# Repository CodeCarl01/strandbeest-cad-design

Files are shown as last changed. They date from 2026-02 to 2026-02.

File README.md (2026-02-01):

# 🦿 Strandbeest — Mécanisme de Jansen imprimé en 3D

**Conception, fabrication et tests d'un Strandbeest mécanique autonome — 0% électronique, 100% mécanique.**

Projet académique de 1ère année cycle ingénieur à Polytech Dijon. Un robot marcheur inspiré du mécanisme de Theo Jansen, entièrement conçu en CAO sous SolidWorks, fabriqué par impression 3D et propulsé par une corde élastique. Budget total : **15,82 €**.






---

<!-- Ajouter ici une photo ou un GIF du Strandbeest en mouvement -->
<!-- ![Demo](docs/strandbeest-demo.gif) -->

## 📋 Sommaire

- [Le projet](#-le-projet)
- [Mécanisme de Jansen](#-mécanisme-de-jansen)
- [Conception CAO](#-conception-cao)
- [Fabrication](#-fabrication)
- [Résultats des tests](#-résultats-des-tests)
- [Bill of Materials](#-bill-of-materials)
- [Limites et améliorations](#-limites-et-améliorations)
- [Équipe](#-équipe)

---

## 🎯 Le projet

### Cahier des charges

| Critère | Exigence | Résultat |
|---|---|---|
| Parcourir 30 cm minimum | ✅ Requis | **65 cm** atteints (4,5 tours) |
| Temps sur 30 cm | ~10 secondes | ✅ Validé |
| Stabilité | Marche stable sur sol plat | ✅ Validé |
| Cycle complet sans blocage | ✅ Requis | ✅ Validé |
| Aucune électronique | ✅ Obligatoire | ✅ Respecté |
| Budget < 100 € | ✅ Obligatoire | **15,82 €** |

### Principe de fonctionnement

```
  Clé de remontage
       │
       ▼
┌─────────────────┐
│  Corde élastique │  ← Stockage d'énergie (25 J, rendement ~70%)
│    (sandow)      │
└────────┬────────┘
         │
         ▼
┌─────────────────┐
│  Système poulie  │  ← Transmission et renvoi d'angle
│  + engrenage     │
└────────┬────────┘
         │
         ▼
┌─────────────────┐
│  Axe principal   │  ← Rotation continue (couple max : 1 N.m)
│  (manivelle)     │
└────────┬────────┘
         │
         ▼
┌─────────────────┐
│  Pattes Jansen   │  ← 4 pattes articulées, mouvement de marche
│  (x4, déphasées) │
└─────────────────┘
```

---

## ⚙️ Mécanisme de Jansen

Le Strandbeest repose sur le mécanisme à barres inventé par Theo Jansen. Chaque patte est composée de tiges rigides reliées par des articulations qui convertissent un mouvement rotatif en une trajectoire de marche.

### Proportions de Jansen (originales → adaptées)

Les 13 longueurs de référence de Jansen ont été adaptées à notre échelle avec un coefficient multiplicateur de **55/38** (base `a` = 55 mm au lieu de 38 mm) :

```
Longueurs originales (mm)        Notre adaptation (mm)
a = 38.0                         a = 55.0 (base)
b = 41.5                         b = 60.1
c = 39.3                         c = 56.9
d = 40.1                         d = 58.0
e = 55.8                         e = 80.7
f = 39.4                         f = 57.0
g = 36.7                         g = 53.1
h = 65.7                         h = 95.1
i = 49.0                         i = 70.9
j = 50.0                         j = 72.4
k = 61.9                         k = 87.0 ⚠️ (modifié, voir ci-dessous)
l =  7.8                         l = 11.3
m = 15.0                         m = 21.7
```

### Modification du paramètre `k`

Lors de la simulation cinématique sous SolidWorks, le mécanisme se bloquait avec les cotes proportionnelles exactes. La valeur `k` (distance axe manivelle – point de pivot) a été augmentée de **57 mm à 87 mm** pour débloquer la cinématique.

**Impact sur la trajectoire :**

| Caractéristique | Modèle Jansen original | Notre adaptation |
|---|---|---|
| Forme de la trajectoire | En "D" (optimale) | Aplatie horizontalement |
| Foulée | Standard | Plus longue |
| Hauteur de levée du pied | Haute (franchit les obstacles) | Basse (rase le sol) |
| Stabilité sol plat | Excellente | Bonne |

Ce compromis a transformé le marcheur en un "glisseur" optimisé pour les surfaces lisses.

---

## 🖥️ Conception CAO

Toutes les pièces ont été modélisées sous **SolidWorks** :

- Modélisation paramétrique des 27 pièces distinctes
- Assemblage complet avec contraintes cinématiques
- Simulation du mécanisme de marche
- Export STL pour impression 3D

### Pièces principales (27 types, 130+ pièces au total)

| Catégorie | Pièces | Quantité |
|---|---|---|
| Pattes | Fémur C, Fémur F, Tibia, Métatarse inf./sup., Patelle | 64 |
| Liaisons | Bielle, Bielle terminale, Entretoise, Circlips | 94 |
| Châssis | Abdomen inf./sup., Pédicelle, Griffe inf./sup. | 12 |
| Transmission | Poulie, Roues (entrée/sortie/libre), Manivelle, Levier | 15 |
| Autres | Clé, Crochet | 2 |

---

## 🏭 Fabrication

### Matériaux et impression 3D

| Matériau | Quantité | Usage | Prix |
|---|---|---|---|
| PLA | 511,22 g | Structure principale, pattes, châssis | 11,75 € |
| ABS | 111,82 g | Pièces soumises à contrainte | 2,57 € |
| Corde élastique (sandow) | 1 m, Ø6 mm | Motorisation | 1,50 € |
| **Total** | | | **15,82 €** |

### Optimisations de coût

- Retrait de matière superflue sur chaque pièce pour réduire le temps et le coût d'impression
- Aucune vis, boulon ou élément de fixation externe — uniquement des liaisons imprimées (circlips, entretoises)
- Résultat : **84% sous le budget** maximum de 100 €

---

## 📊 Résultats des tests

### Distance parcourue vs. nombre de tours de clé

| Tours de clé | Distance (cm) |
|---|---|
| 1 | 10 |
| 2 | 30 |
| 3 | 40 |
| 4 | 53 |
| 4,5 | 65 |

### Performances mesurées

| Métrique | Valeur |
|---|---|
| Distance maximale | **65 cm** (4,5 tours) |
| Vitesse moyenne | **39,55 cm/s** (1,4 km/h) |
| Objectif 30 cm | ✅ Atteint dès 2 tours |
| Stabilité | ✅ Marche stable sur sol plat |
| Cycle complet | ✅ Sans blocage |

---

## ⚠️ Limites et améliorations

| Problème identifié | Cause | Amélioration proposée |
|---|---|---|
| Porte-poulies fragiles | PLA ne résiste pas au couple de la corde | Ajout de nervures (fait) / passage en ABS |
| Clé de remontage mal positionnée | Difficilement accessible | Remplacer par une clé de serrage externe |
| Usure du crochet et engrenage | Frottements PLA/PLA | Matériau plus résistant ou lubrification |
| Limite à 4,5 tours | Le crochet cède sous le couple | Renforcer le mécanisme de retenue |
| Dérapage sur sol lisse | Pieds trop fins | Ajouter des embouts en caoutchouc |

---

## 👥 Équipe

Projet réalisé dans le cadre du **Projet Fil Rouge — Ouverture** (1ère année cycle ingénieur, Polytech Dijon, 2025) :

| Membre | Rôle |
|---|---|
| Alexandre RAFFIN | Conception & fabrication |
| Raphaël MAUL | Conception & fabrication |
| Mamalinesso BAKAI | Conception & fabrication |
| Carl MENSAH | Conception & fabrication |

---

## 📁 Structure du repository

```
strandbeest-cad-design/
├── CAO/
│   ├── Pieces/             # Fichiers SolidWorks (.SLDPRT) de chaque pièce
│   ├── Assemblage/         # Assemblage complet (.SLDASM)
│   └── STL/                # Fichiers STL prêts pour impression 3D
├── docs/
│   ├── rapport-technique.pdf
│   └── screenshots/        # Captures CAO et photos du Strandbeest
├── tests/
│   └── resultats.md        # Données brutes des tests de performance
└── README.md
```

---

## 📜 Licence

Projet académique — Polytech Dijon, 2025.

---

*Inspiré par les créatures de plage de [Theo Jansen](https://www.strandbeest.com/) 🌊*

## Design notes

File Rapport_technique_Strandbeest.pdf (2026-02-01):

Livrable

# Projet fil rouge -Ouverture

Rapport technique

### Alexandre RAFFIN | Raphaël MAUL | Mamalinesso BAKAI | Carl MENSAH

10/12/2025

## 1. Cahier des Charges – Contraintes

Contexte :

Dans le cadre du projet d’ouverture en 1ère année d’école d’ingénieur à Polytech Dijon nous devons concevoir un strandbeest, inspiré par le mécanisme de Jansen, Cela nous permettra d’en apprendre plus sur la conception mécanique et la fabrication additive.

Fonction principale attendue :

Le strandbeest doit être capable d’avancer de manière autonome et stable grâce à un système d’entrainement mécanique.

Contraintes :

Aucune électronique ne doit être utilisée.

Les pièces principales du strandbeest doivent être créées en CAO uniquement et les pièces complémentaires sont autorisées si elles sont justifiées.

Optimiser les coûts de fabrication pour minimiser le budget. Inférieur à 100 €.

Le strandbeest doit être réalisé avec une échelle minimaliste soit environ 30 cm d’envergure.

Le strandbeest doit être capable d’avancer sur un sol plat sans qu’aucune des pièces ne se casse.

Critères d’évaluation :

Le strandbeest doit parcourir au minimum 30 cm sur sol plat.

Le strandbeest doit parcourir les 30 cm en environ 10 secondes

Le strandbeest doit être stable.

Le mécanisme devra réaliser un cycle de marche complet sans blocage.

Livrables attendus :

- Fichiers CAO fournis au format STL pour impression 3D.
- Fichiers Imprimables
- Simulation, résultats + captures vidéo

- Matériel + prix
- Strandbeest assemblé et fonctionnel
- Vidéo de démo
- Diapo

## 2. Étude du mécanisme de Jansen

Le mécanisme de Jansen, inventé par l’artiste et ingénieur néerlandais Theo Jansen, est à la base du mouvement du célèbre strandbeest . L’objectif de Jansen était de créer une structure mécanique capable de marcher de manière fluide et stable grâce à un simple mouvement rotatif et sans aucune électronique à l’intérieur. Pour cela, il a développé un système de pattes articulées dont les dimensions sont calculées avec une grande précision.

Principe général :
Le mécanisme repose sur la conversion d’un mouvement circulaire en un mouvement alternatif des pattes. Chacune des différentes pattes est constituée de plusieurs tiges rigides reliées par des entretoises. De ce fait, lorsque l’axe tourne, les articulations suivent une trajectoire spécifique qui reproduit la marche.
L’idée essentielle est que la trajectoire de la patte doit suivre un mouvement plat et régulier : la patte doit rester presque horizontal pendant la phase d’appui au sol, puis se relever pour passer à la phase de retour. Cela permet au strandbeest d’avancer sans trop d’oscillations et par conséquent, d'avoir une bonne stabilité.

Le théorème de Jansen :

Theo Jansen pour aboutir à ses recherches est donc passé par des expérimentations et de nombreuses modélisations, pour réussir à obtenir un ensemble optimal de longueurs pour les tiges de chaque patte. Par conséquent, il a fini par déterminer 13 longueurs spécifiques (nommées A à M) qui permettent d’obtenir un mouvement fluide et efficace.
Mais, ces longueurs ne respectent en aucun cas un théorème d'un point de vue mathématique, car il a utilisé un modèle géométrique empirique pour définir la cinématique idéale de la marche.

Voici, à titre indicatif, les rapports de longueurs de base obtenu par Jansen :

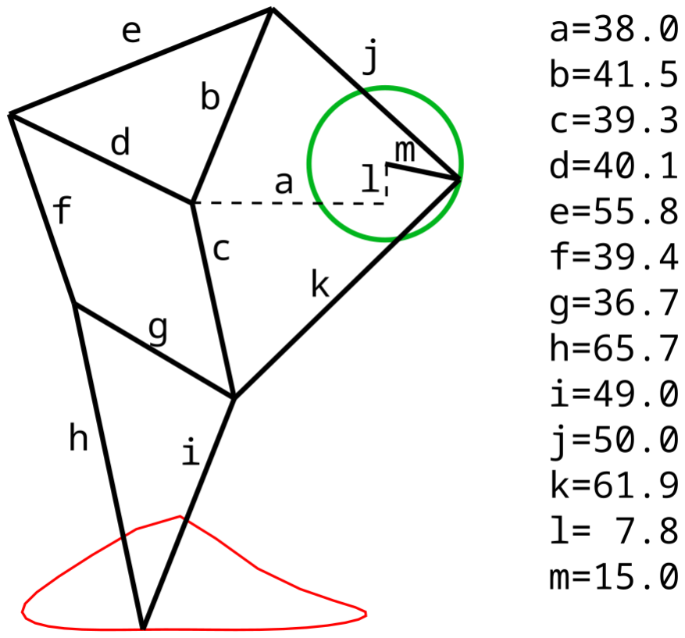
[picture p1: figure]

Ces valeurs permettent à la patte de suivre une trajectoire ovale dont la partie inférieure reste presque parallèle au sol. Ainsi, le robot avance de manière continue lorsque plusieurs pattes sont déphasées autour du même axe.

Etude de la trajectoire :

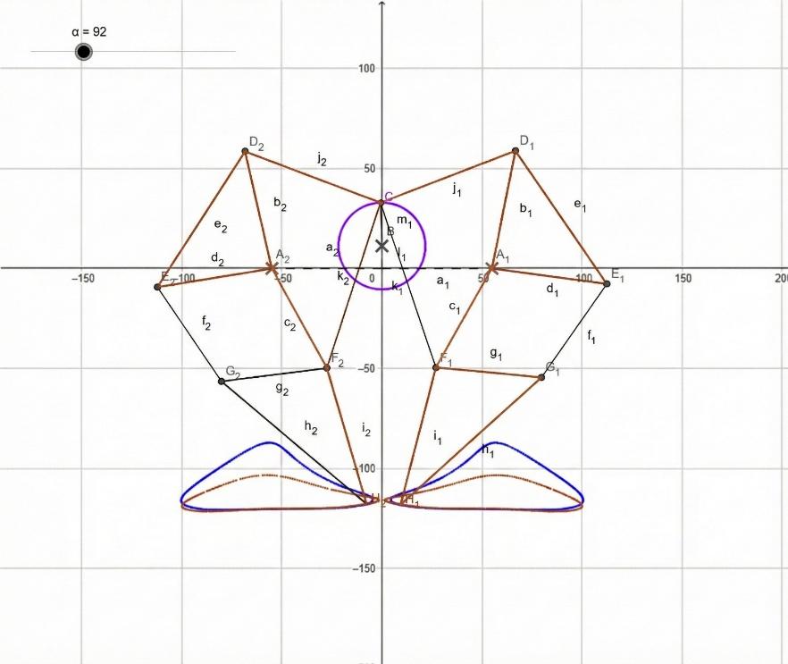
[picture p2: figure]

Dans notre projet, nous sommes partis d'une intention rigoureuse : adapter les "nombres sacrés" de Theo Jansen à notre propre échelle. Puisque nous avons fixé notre base a à 55 mm contre 38 mm pour le modèle original, nous avons appliqué un coefficient multiplicateur de 55
38

à toutes les autres longueurs. Théoriquement, cela aurait dû nous donner une courbe identique à la référence bleue, simplement plus grande. Cependant, nous avons rencontré un blocage technique lors de la simulation sur SolidWorks, le mécanisme refusant de tourner avec les cotes proportionnelles exactes. Pour débloquer la cinématique et permettre le mouvement, nous avons pris la décision de modifier significativement la valeur k, qui représente la distance entre l'axe de la manivelle et le point de pivot de la jambe. Alors que le calcul proportionnel nous donnait un k autour de 57 mm, nous l'avons passé à 87 mm, et c'est cette modification majeure qui explique la forme singulière de notre courbe marron.

En analysant notre résultat par rapport à la courbe bleue de référence, l'impact de ce k étiré est flagrant. La courbe bleue possède cette forme optimale en "D", avec une base plate pour la stabilité et une arche haute pour le retour du pied. Notre courbe marron, en revanche, s'est retrouvée comme "écrasée" verticalement et étirée horizontalement. En éloignant le point de pivot (en augmentant k), nous avons forcé le mécanisme à travailler dans une configuration plus ouverte, ce qui a eu pour effet d'aplatir la trajectoire du pied. Nous avons réussi à obtenir un mouvement fluide dans le logiciel, mais nous avons perdu la hauteur caractéristique du pas du Strandbeest.

Concrètement, cela donne à notre robot des caractéristiques de déplacement différentes du modèle original. La partie inférieure de notre courbe marron, qui correspond au moment où le pied touche le sol, est très allongée. Cela signifie que notre Strandbeest aura une foulée très longue ; il parcourra plus de distance à chaque tour de manivelle que s'il avait la courbe bleue. C'est un point potentiellement positif pour la vitesse sur un sol parfaitement lisse. Cependant, on remarque que cette ligne de sol n'est pas parfaitement droite, elle est légèrement bombée, ce qui risque de faire dandiner le robot de haut en bas pendant la marche, là où la courbe bleue assure une hauteur de hanche quasi constante.

Le véritable compromis de notre choix technique se situe au niveau de la phase de retour, c'est-à-dire la partie supérieure de la boucle. Sur la courbe bleue, le pied remonte haut, ce qui permet à la créature d'enjamber le sable ou les obstacles. Sur notre courbe marron, la phase de retour rase le sol, passant très près de la phase d'appui. En modifiant k pour satisfaire les contraintes de SolidWorks, nous avons transformé un "marcheur tout-terrain" en un "glisseur". Notre robot sera fonctionnel, mais il sera probablement vulnérable aux irrégularités du terrain, car il ne lèvera pas assez les pieds pour éviter de trébucher sur des obstacles que le modèle de référence aurait franchis sans problème.

## 3. Calculs de dimensionnement

Propriétés de la corde élastique

Le système repose sur une corde élastique (sandow) d'une longueur au repos L₀ de 1,0 mètre et d'un diamètre de 6 millimètres. Ce diamètre, relativement important pour du modélisme, laisse présager une capacité de force intéressante.

La caractéristique fondamentale de ce composant est sa constante de raideur (k). En se basant sur les données techniques, une force d'environ 40 à 50 Newtons est nécessaire pour doubler la longueur d'un tel sandow. Nous retiendrons donc pour cette analyse une valeur moyenne de : k ≈ 50 N/m

Concrètement, cela signifie que pour chaque mètre d'étirement, la corde oppose une force de rappel de 50 Newtons, ce qui équivaut à la force requise pour soulever une masse de 5 kg.

Modélisation de la force et de l'énergie

- Comportement en traction et loi de Hooke

Dans sa plage d'utilisation normale, la corde suit un comportement élastique linéaire. La force de rappel F est donc directement proportionnelle à son allongement ΔL. En étirant la corde de 1 mètre (pour une longueur totale de 2 mètres), la force maximale que le système pourra restituer au démarrage sera de :

Fmax = k × ∆L = 50 × 1 = 50 N

- Limites d'utilisation

Il est important de comprendre les limites de ce matériau. La longueur maximale d'un sandow est généralement contrainte par sa gaine protectrice, autour de 150 % d'allongement (soit 2,5 m au total). À l'approche de cette limite, la force augmente de manière exponentielle et peut atteindre 80 à 100 Newtons. Solliciter la corde dans cette zone extrême est cependant déconseillé, car cela accélère son usure et crée un risque de rupture pour la structure du strandbeest.

- Énergie potentielle stockée

L'énergie accumulée dans la corde tendue, qui sera ensuite convertie en mouvement, est l'énergie potentielle élastique (Epe). Elle se calcule avec la formule :

Epe =

1
2

k × (∆L)

2

Pour un allongement de 1 mètre, l'énergie stockée s'élève à :

Epe =

1
2

× 50 × (1)

2

Pour mettre ce chiffre en perspective, 25 Joules représentent l'énergie nécessaire pour soulever une masse de 2,5 kg à un mètre de hauteur. C'est une quantité d'énergie tout à fait considérable pour une maquette, capable de la propulser sur une distance correcte.

Le rendement énergétique : hystérésis

Le modèle théorique doit être nuancé par la réalité matérielle. Les cordes élastiques sont sujettes au phénomène d'hystérésis : une partie de l'énergie fournie lors de l'étirement est inévitablement dissipée en chaleur lors du relâchement. Pour un sandow, le rendement énergétique se situe entre 60 % et 70 %. L'énergie réellement disponible (Eutile) pour le mécanisme sera donc plus faible :

Eutile ≈ 25 Joules × 0,7 = 17,5 Joules

Il est donc crucial de prendre en compte cette perte lors du dimensionnement de la transmission pour garantir un fonctionnement fluide et éviter que le mécanisme ne se bloque.

Application mécanique : le couple moteur

La transformation de la force de traction en rotation s'effectue en enroulant la corde autour d'un axe. Le couple (C), qui est la force de rotation, dépend alors du rayon r de cet axe, selon la relation :

C = F × r

Avec un axe d'un rayon de 2 cm, le couple varie de cette façon :

- Au démarrage (force maximale) : Cmax = 50 × 0,02 = 1 N. m
- À mi-course : La force et donc le couple sont réduits de moitié, tombant à 0,5 N. m

Un couple initial de 1 N.m est important pour de la petite mécanique. Cependant, il est essentiel de retenir que ce couple n'est pas constant. Par conséquent, le mouvement du strandbeest se caractérisera par une forte accélération au départ, suivie d'un ralentissement progressif à mesure que la corde se détend.

Conclusion et recommandations

Notre analyse confirme que l'utilisation d'une corde élastique est une solution pertinente pour la motorisation d'un strandbeest. Elle offre une réserve d'énergie intéressante et un couple de démarrage élevé.

## 4. Gestion des coûts

Stratégie de minimisation des coûts

Pour respecter la contrainte budgétaire du projet d'ouverture, nous avons mis en place plusieurs procédés pour essayer de réduire au maximum les coûts. Nous avons choisi dans un premier temps, d’utiliser principalement l'impression 3D pour fabriquer la quasi-totalité des pièces puisque cela permet de minimiser grandement les coûts de matière, en utilisant en grande majorité du PLA et de l’ABS. De plus nos modèles ont été optimiser au maximum en retirant toute matière inutile ce qui permet des réduire la quantité de filaments utilisés et donc de réduire les coûts, ainsi que, réduire le temps d'impression. De même nous avons également fais en sorte de ne pas utiliser de vis, de boulon ou d'autres éléments de fixation afin de ne pas augmenter le budget. Tout cela nous a donc permis de rester très largement sous la limite des 100€ maximums indiqués, tout en gardant un strandbeest robuste et fonctionnel.

Bill of Materials & Bill of Pieces

N° du matériau | Nom du matériau | Quantité | Prix
1 | PLA | 511,22 g | 11,75 €
2 | ABS | 111,82 g | 2,57 €
3 | Corde élastique | 1 | 1,50 €

Le montant total de notre strandbeest est donc de : 15,82 €

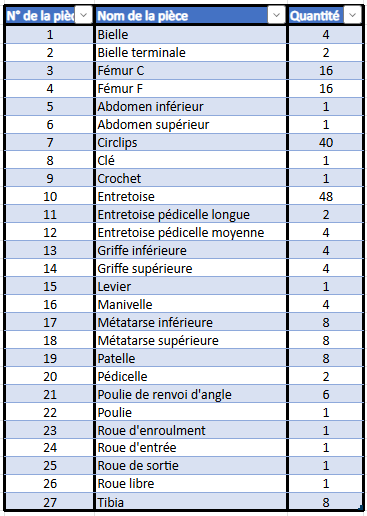
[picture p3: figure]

## 5. Tests et méthode d’évaluation

Voici les distances parcourues par le strandbeest suivant le nombre de tours effectués par la clé :

Nombre de tours | Distance parcourue (cm)
1 | 10
2 | 30
3 | 40
4 | 53
4,5 | 65

Nous obtenons donc une vitesse moyenne après calcul suivant le nombre de tours
de : 33,7cm/s | 48,8cm/s | 38,9cm/s | 36,8 ce qui donne finalement une moyenne
globale de : 39,55cm/s soit 1,4km/h

## 6. Discussion sur les limites et amélioration possibles

Il y a des limites observées et de nombreuses pistes d’amélioration possibles :

- La résistance des portes poulies renvoie d’angle est limité par l’utilisation du PLA qui ne résiste pas à la force exercée par la corde une fois celle-ci remonté. Pour régler ce problème, nous avons donc rajouté des nervures sur les portes poulies pour que ceux-ci soient plus solides.
- La clé de remontage est aussi assez mal positionnée et ne permet pas de bien faire tendre la corde car elle est difficilement accessible. Pour régler cet inconvénient, on pourrait utiliser une sorte de clé de serrage à la place de notre clé actuelle qui serait alors plus facilement atteignable.
- Le crochet et l’engrenage permettant la remonté mécanique finissent par se rogner petit à petit à cause des frottements, ce qui fait que le crochet à de plus en plus de mal pour retenir la corde tendue. De plus, au bout de quatre tours et demi le crochet n’est plus assez solide pour retenir le couple exercé par la corde.
- Le bout des pattes empêchent une bonne adhérence à cause de leur finesse sur des surfaces lisses et le strandbeest à alors tendance à déraper.

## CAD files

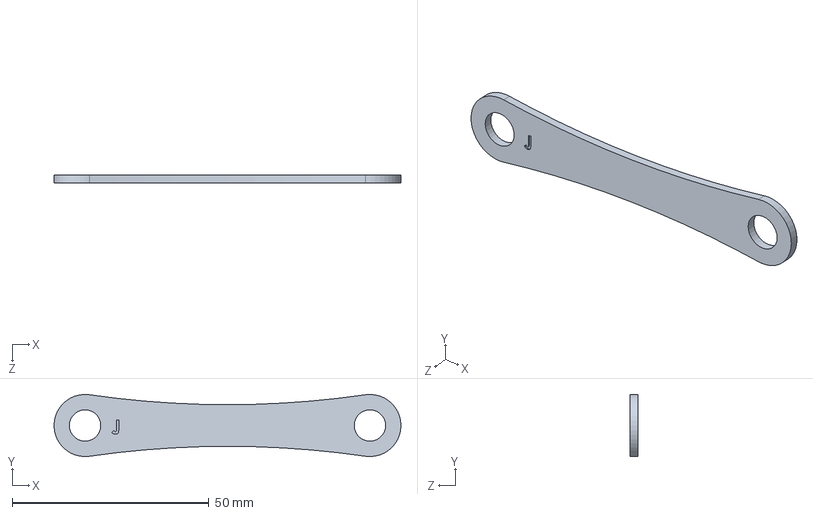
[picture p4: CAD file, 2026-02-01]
Strandbeest_fichiers_CAO/patella.SLDPRT
88.1 x 15.8 x 2.00 mm

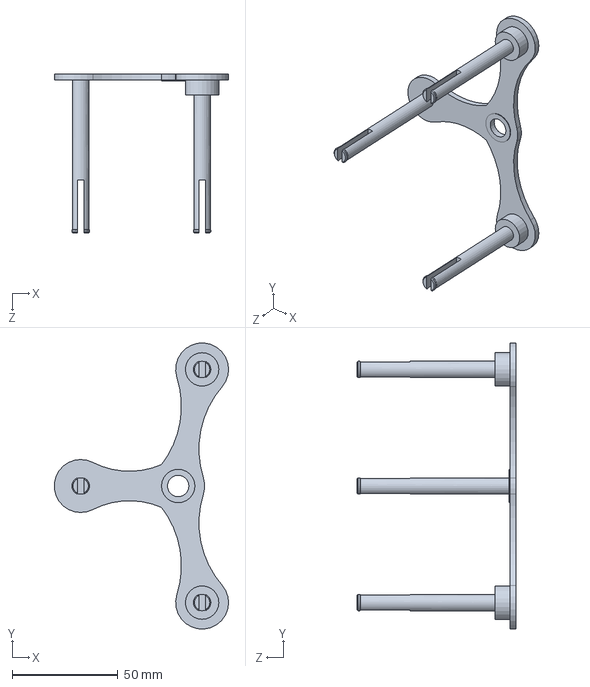
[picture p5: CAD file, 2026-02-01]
Strandbeest_fichiers_CAO/pedicelle.SLDPRT
82.2 x 134.9 x 75.1 mm

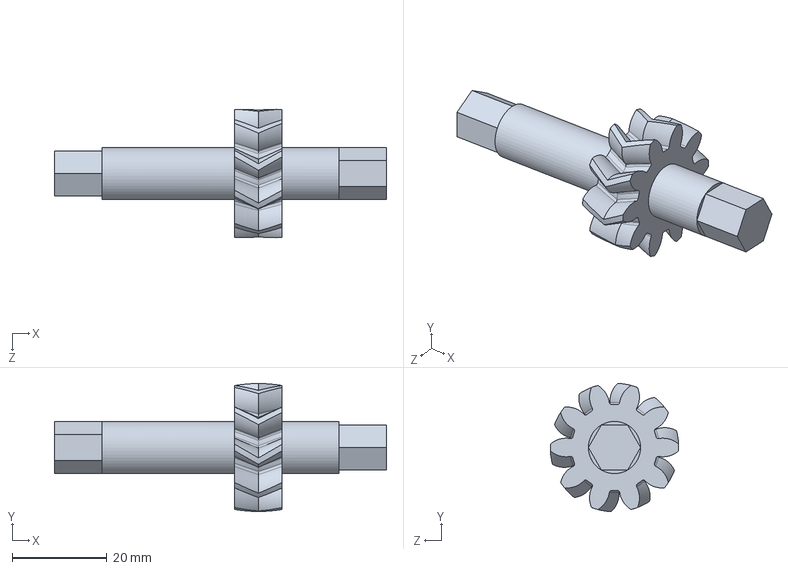
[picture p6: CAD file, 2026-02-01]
Strandbeest_fichiers_CAO/roue d'entree.SLDPRT
70.0 x 27.1 x 27.1 mm

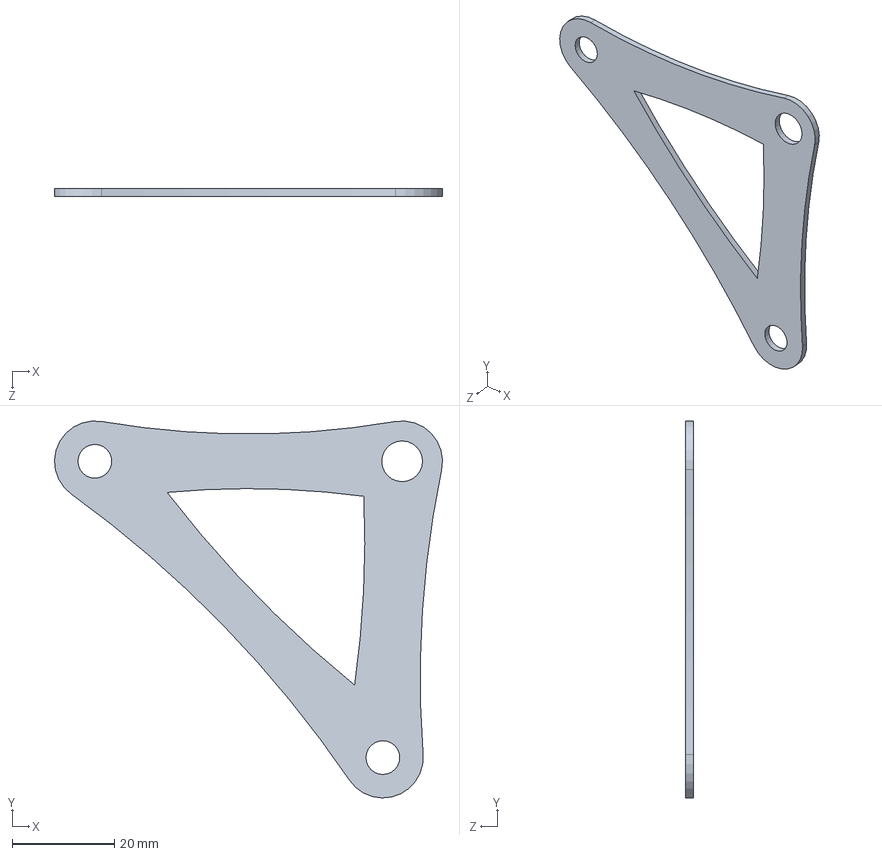
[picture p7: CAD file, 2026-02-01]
Strandbeest_fichiers_CAO/metatarse_sup_D.SLDPRT
75.8 x 73.7 x 1.58 mm

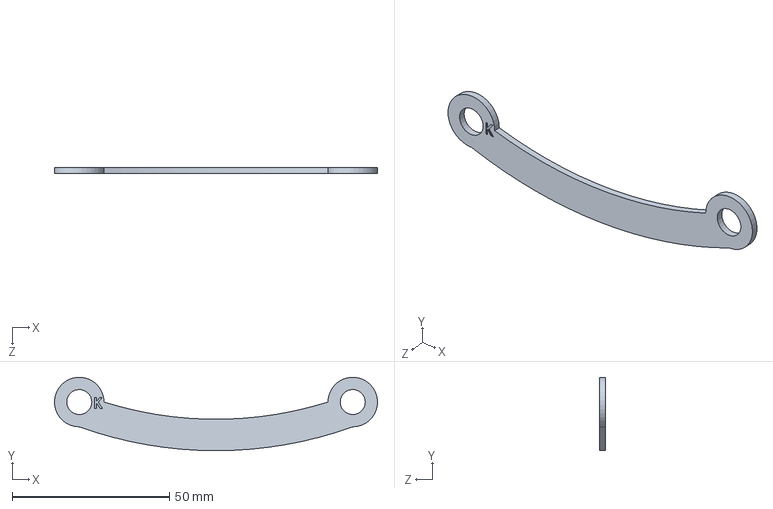
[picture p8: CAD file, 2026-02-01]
Strandbeest_fichiers_CAO/tibia.SLDPRT
102.8 x 23.4 x 2.00 mm

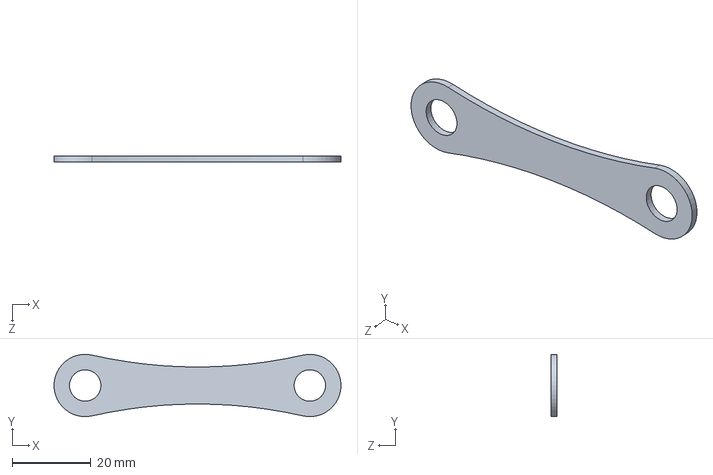
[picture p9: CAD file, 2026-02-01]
Strandbeest_fichiers_CAO/carpe c_D.SLDPRT
72.7 x 15.7 x 1.58 mm

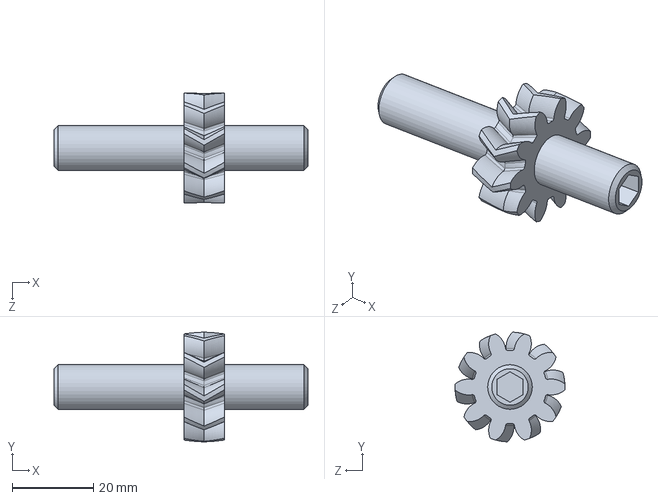
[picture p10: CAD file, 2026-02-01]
Strandbeest_fichiers_CAO/roue de sortie.SLDPRT
62.6 x 27.1 x 27.1 mm

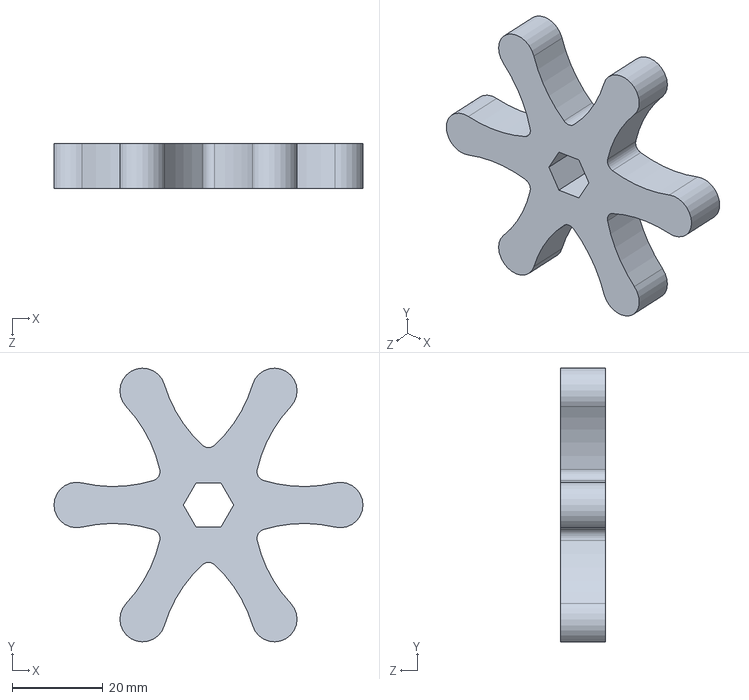
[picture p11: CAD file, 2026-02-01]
Strandbeest_fichiers_CAO/cle.SLDPRT
68.0 x 60.2 x 10.0 mm

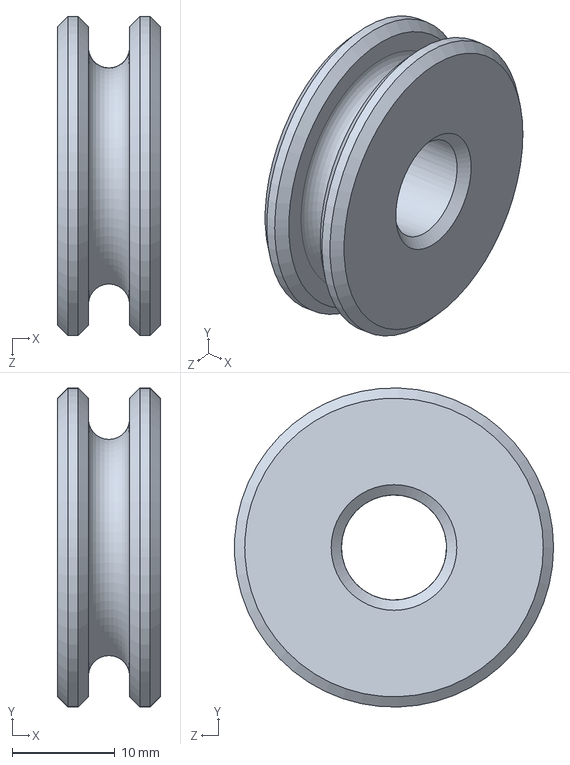
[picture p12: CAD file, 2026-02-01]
Strandbeest_fichiers_CAO/poulie renvoie d'angle.SLDPRT
10.0 x 31.0 x 31.0 mm

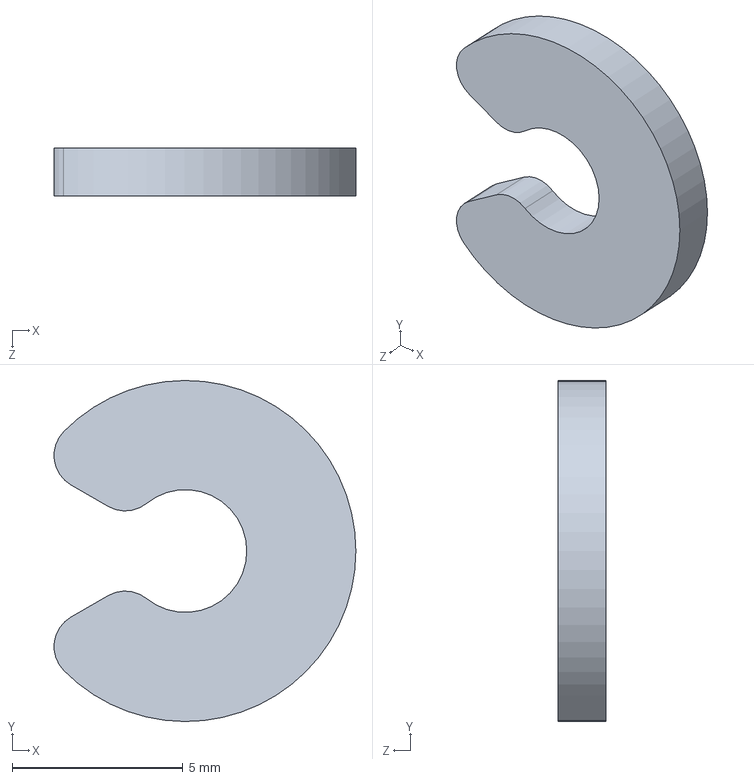
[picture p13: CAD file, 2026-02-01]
Strandbeest_fichiers_CAO/circlips2.SLDPRT
8.85 x 10.00 x 1.40 mm

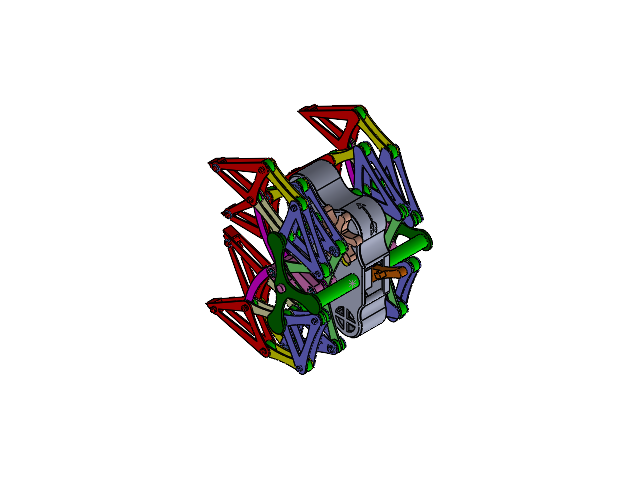
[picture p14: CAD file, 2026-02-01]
Strandbeest_fichiers_CAO/assemblage strandbeest.SLDASM
entretoise c_F x 28
Griffe x 4
griffe_sup x 4
tibia x 8
carpe c x 8
carpe f x 8
metatarse x 4
metatarse_sup x 4
entretoise E_B_J x 4
patella x 8
Griffe_D x 4
griffe_sup_D x 4
carpe c_D x 8
carpe f_D x 8
metatarse_D x 4
metatarse_sup_D x 4
entretoise J_E_D x 8
entretoise I_K_2P x 4
entretoise I_K_2P_D x 4
circlips2 x 21
pedicelle x 2
entretoise pedicelle_Long x 2
entretoise pedicelle_Moyen x 4
bielle x 2
manivelle x 2
bielle_2P x 2
bielle_terminale x 2
manivelle_2P x 2
carter_sup
poulie renvoie d'angle x 6
roue d'enroulement
levier
roue libre
roue de sortie
poulie
crochet
roue d'entree
cle
carter inf

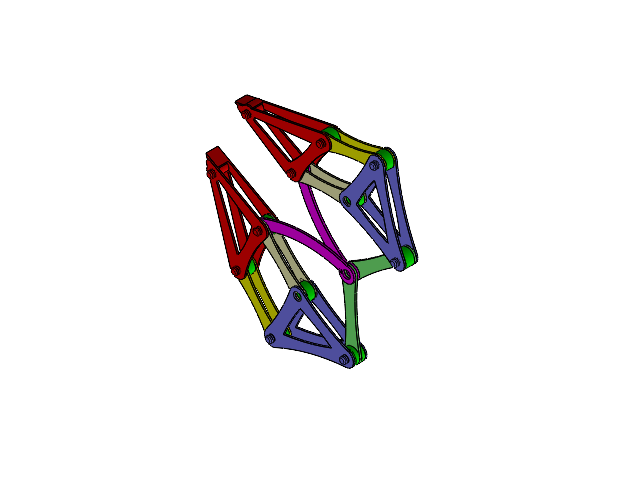
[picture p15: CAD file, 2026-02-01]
Strandbeest_fichiers_CAO/Assemblage pattes_1P_2.SLDASM
entretoise c_F x 6
Griffe
griffe_sup
tibia x 2
carpe c x 2
carpe f x 2
metatarse
metatarse_sup
entretoise E_B_J
patella x 2
Griffe_D
griffe_sup_D
carpe c_D x 2
carpe f_D x 2
metatarse_D
metatarse_sup_D
entretoise J_E_D x 2
entretoise I_K_2P
entretoise I_K_2P_D

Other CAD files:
Strandbeest_fichiers_CAO/Assemblage pattes_2P.SLDASM
Strandbeest_fichiers_CAO/Assemblage Moteur.SLDASM
Strandbeest_fichiers_CAO/Assemblage support pattes.SLDASM
Strandbeest_fichiers_CAO/Assemblage pattes_1P.SLDASM
Strandbeest_fichiers_CAO/Assemblage cames.SLDASM
Strandbeest_fichiers_CAO/carpe f_D.SLDPRT
Strandbeest_fichiers_CAO/Griffe.SLDPRT
Strandbeest_fichiers_CAO/Griffe_D.SLDPRT
Strandbeest_fichiers_CAO/bielle.SLDPRT
Strandbeest_fichiers_CAO/bielle_2P.SLDPRT
Strandbeest_fichiers_CAO/bielle_terminale.SLDPRT
Strandbeest_fichiers_CAO/carpe c.SLDPRT
Strandbeest_fichiers_CAO/carpe f.SLDPRT
Strandbeest_fichiers_CAO/carter inf.SLDPRT
Strandbeest_fichiers_CAO/carter_sup.SLDPRT
Strandbeest_fichiers_CAO/crochet.SLDPRT
Strandbeest_fichiers_CAO/entretoise E_B_J.SLDPRT
Strandbeest_fichiers_CAO/entretoise I_K_2P.SLDPRT
Strandbeest_fichiers_CAO/entretoise I_K_2P_D.SLDPRT
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

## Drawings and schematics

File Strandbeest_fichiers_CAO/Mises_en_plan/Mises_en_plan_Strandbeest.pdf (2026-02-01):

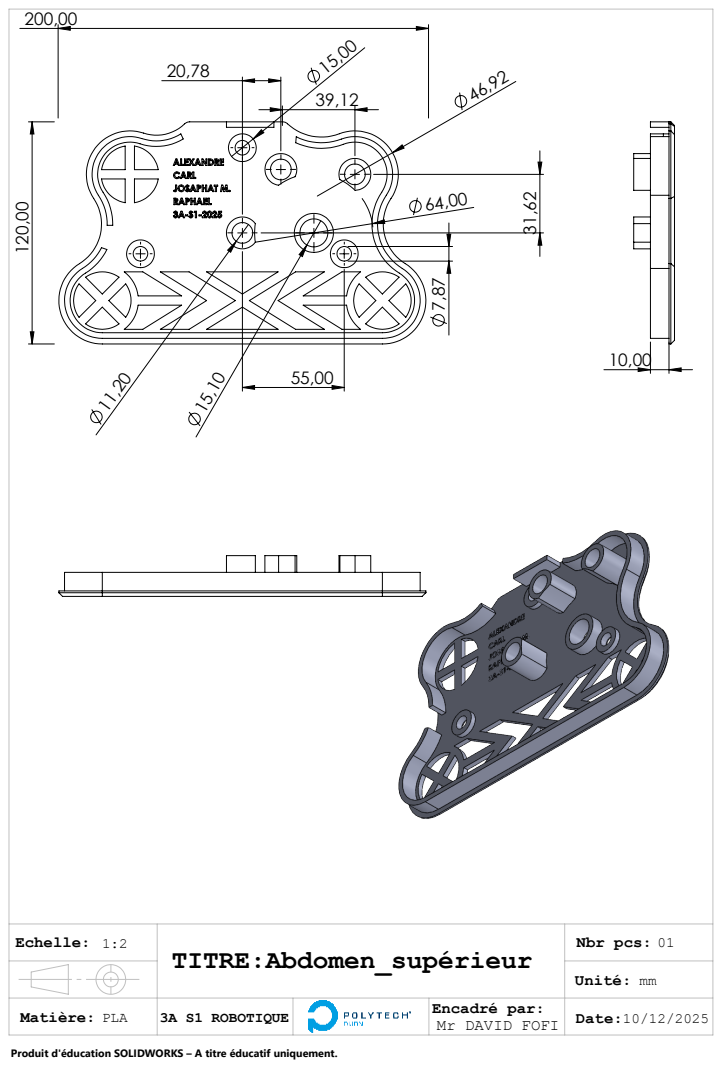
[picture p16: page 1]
Nbr pcs:; 3A S1 ROBOTIQUE

Encadré par:
Mr DAVID FOFI

Produit d'éducation SOLIDWORKS – A titre éducatif uniquement.

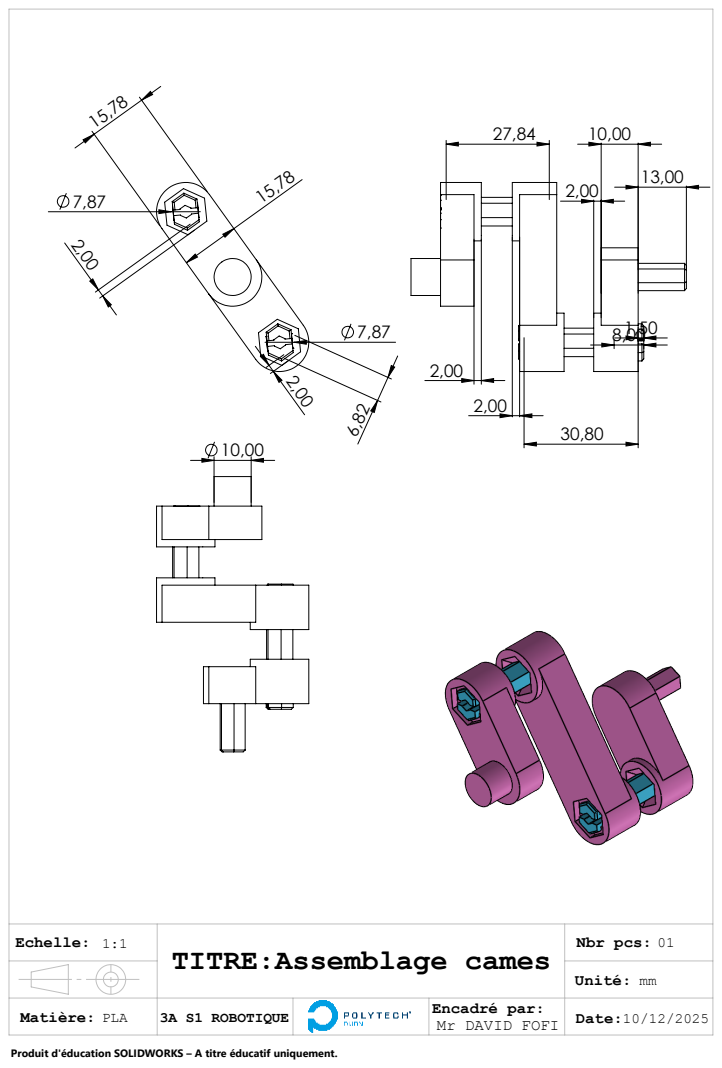
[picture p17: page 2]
Nbr pcs:

Echelle:
Unité: TITRE:Assemblage cames

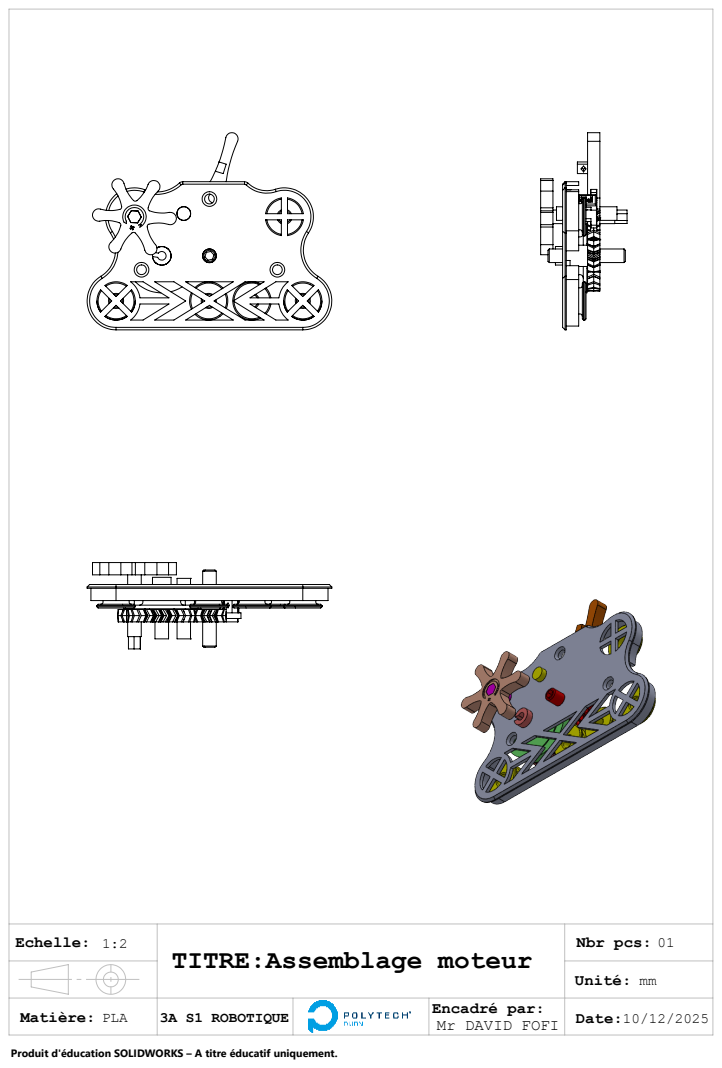
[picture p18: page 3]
Nbr pcs:

TITRE:Assemblage moteur

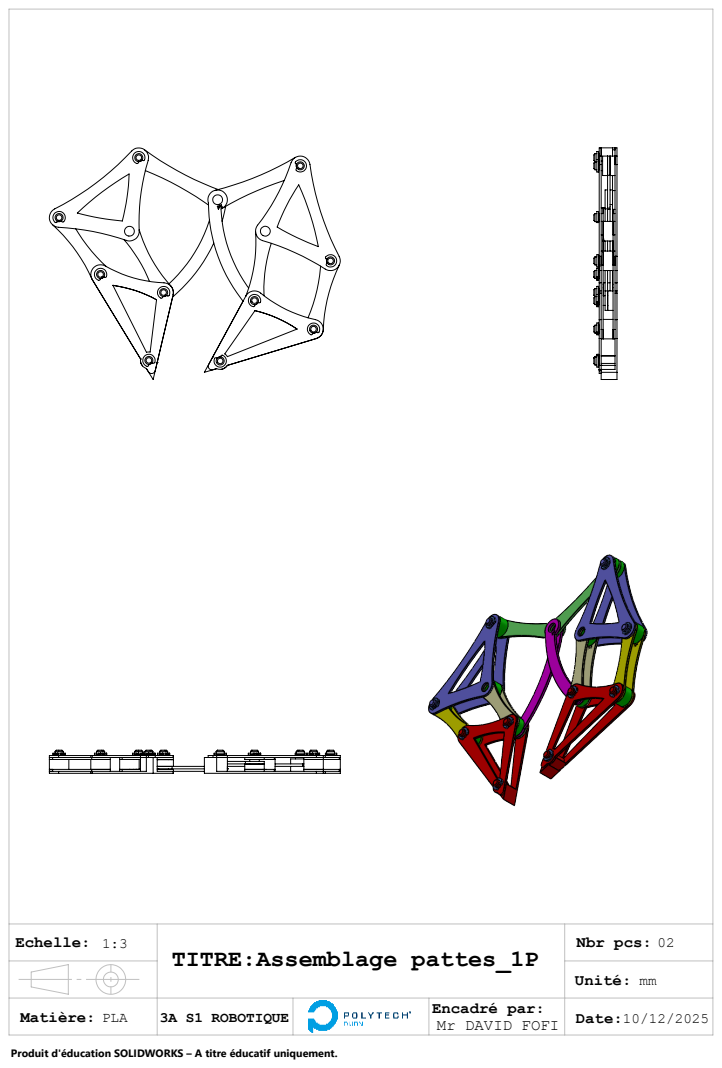
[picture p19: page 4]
Nbr pcs:; TITRE:Assemblage pattes_1P

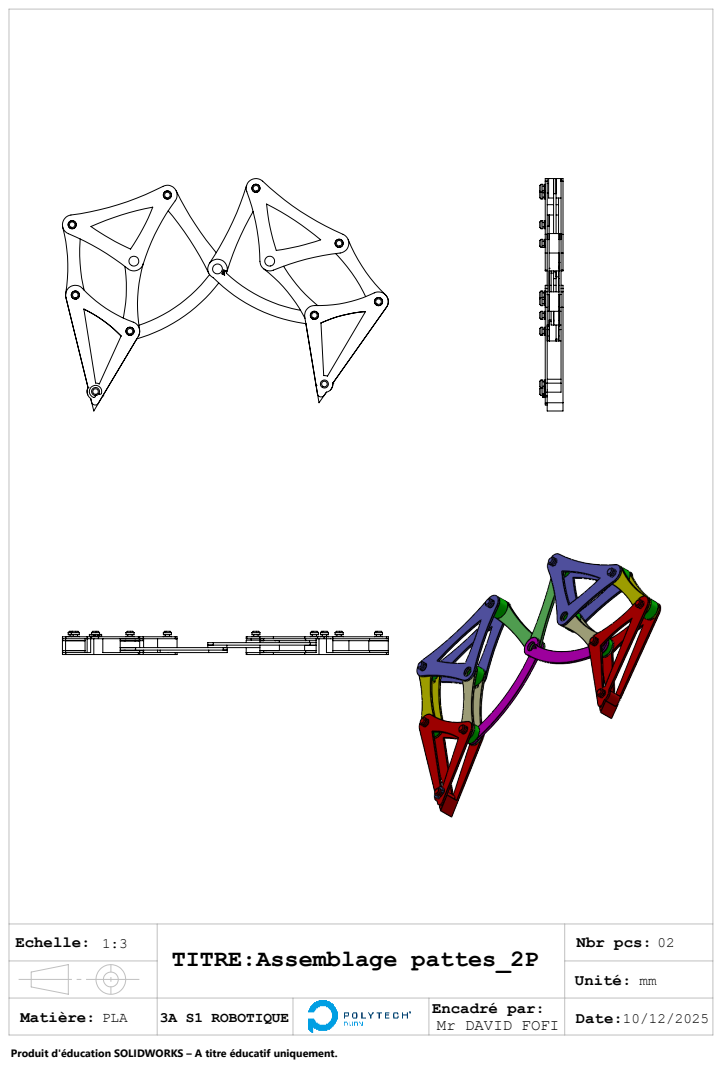
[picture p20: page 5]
Nbr pcs:; TITRE:Assemblage pattes_2P

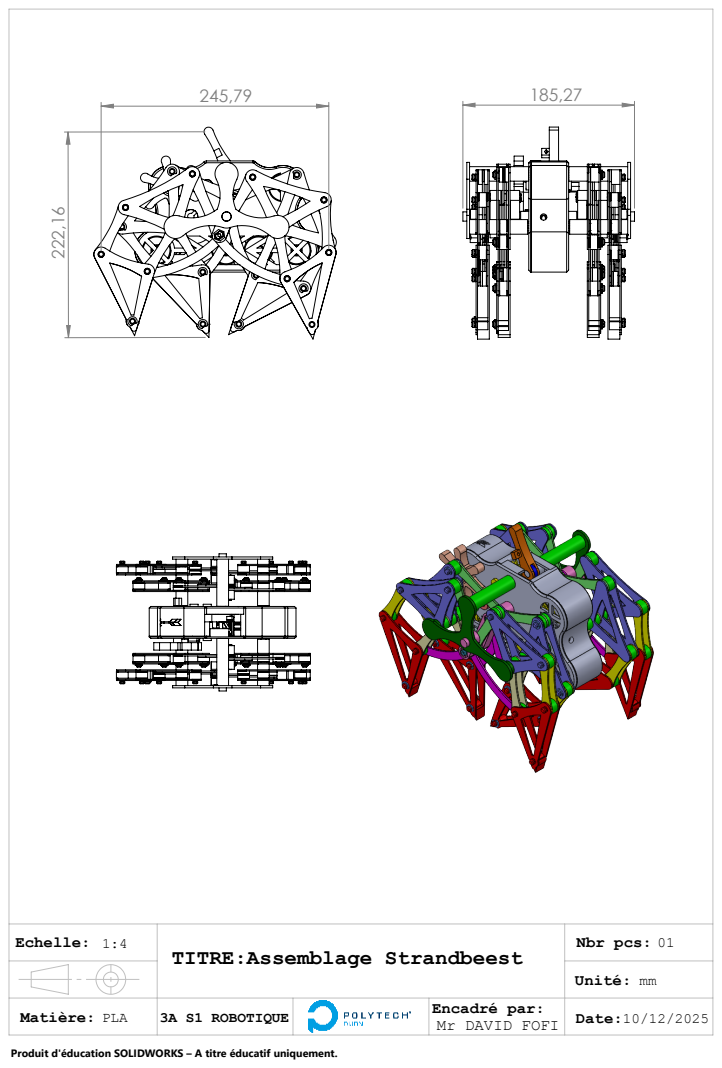
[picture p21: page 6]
Nbr pcs:

TITRE:Assemblage Strandbeest

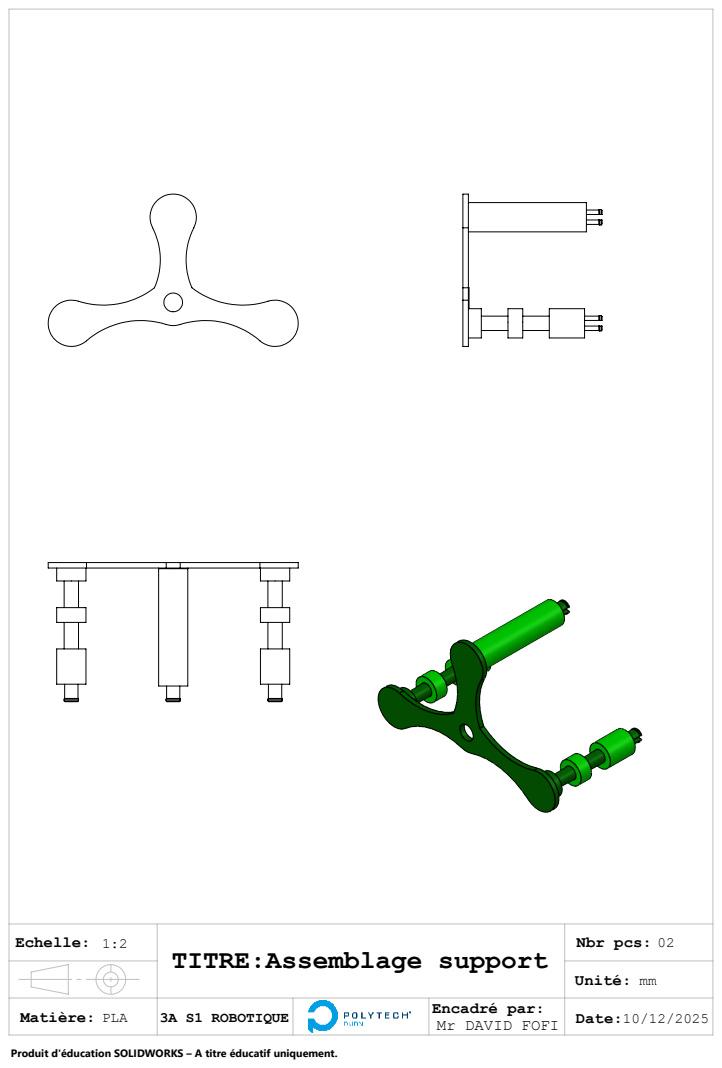
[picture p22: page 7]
Nbr pcs:

TITRE:Assemblage support

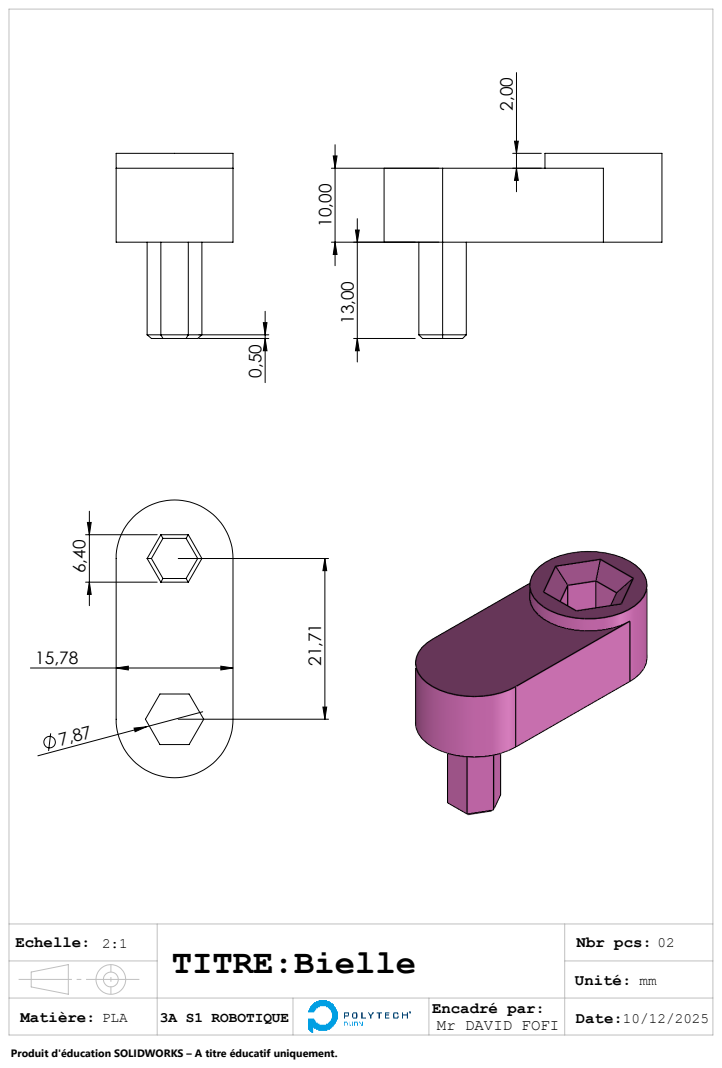
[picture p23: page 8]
Nbr pcs:

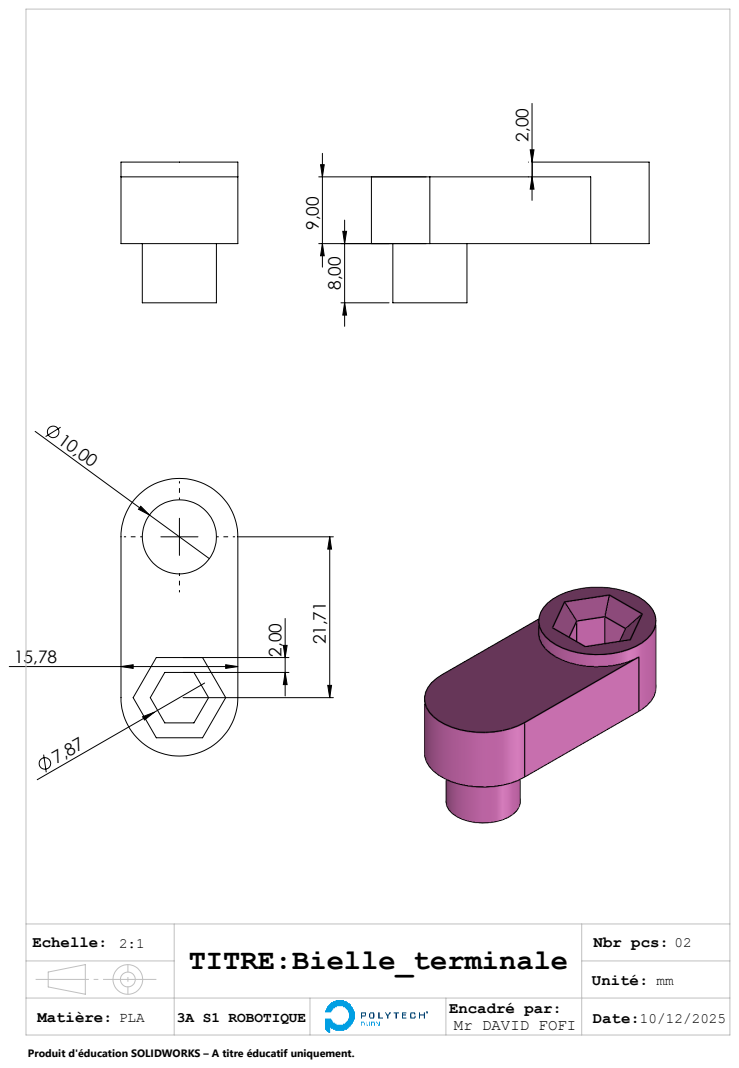
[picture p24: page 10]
Nbr pcs: Unité: TITRE:Bielle_terminale

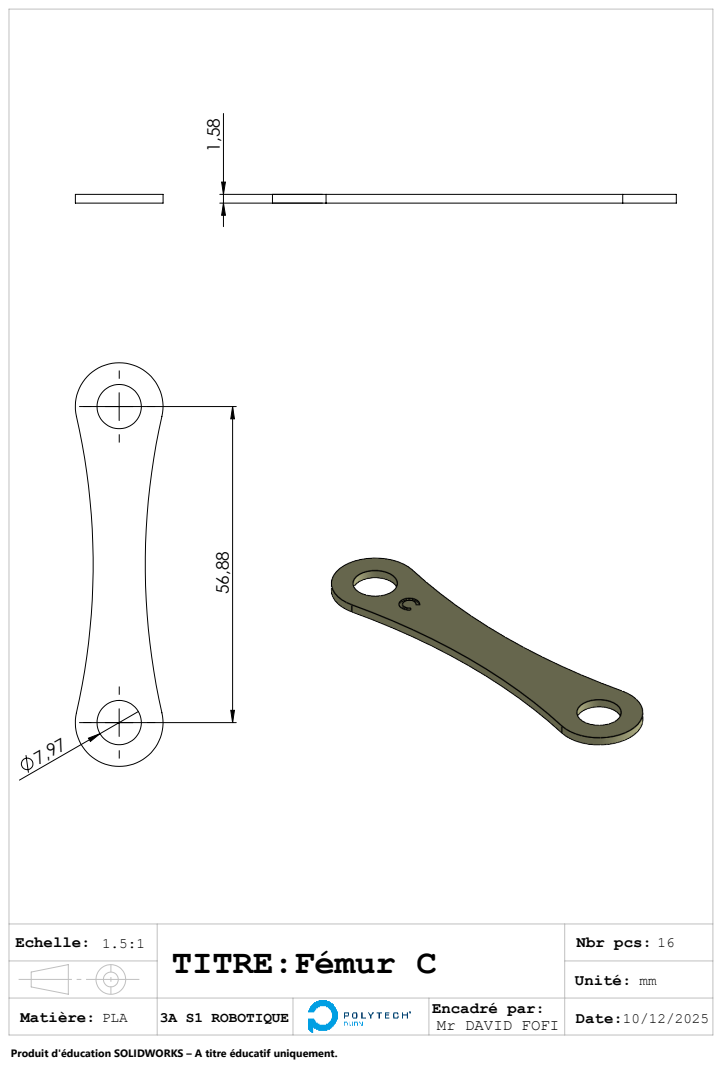
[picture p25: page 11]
Nbr pcs:; TITRE:Fémur C

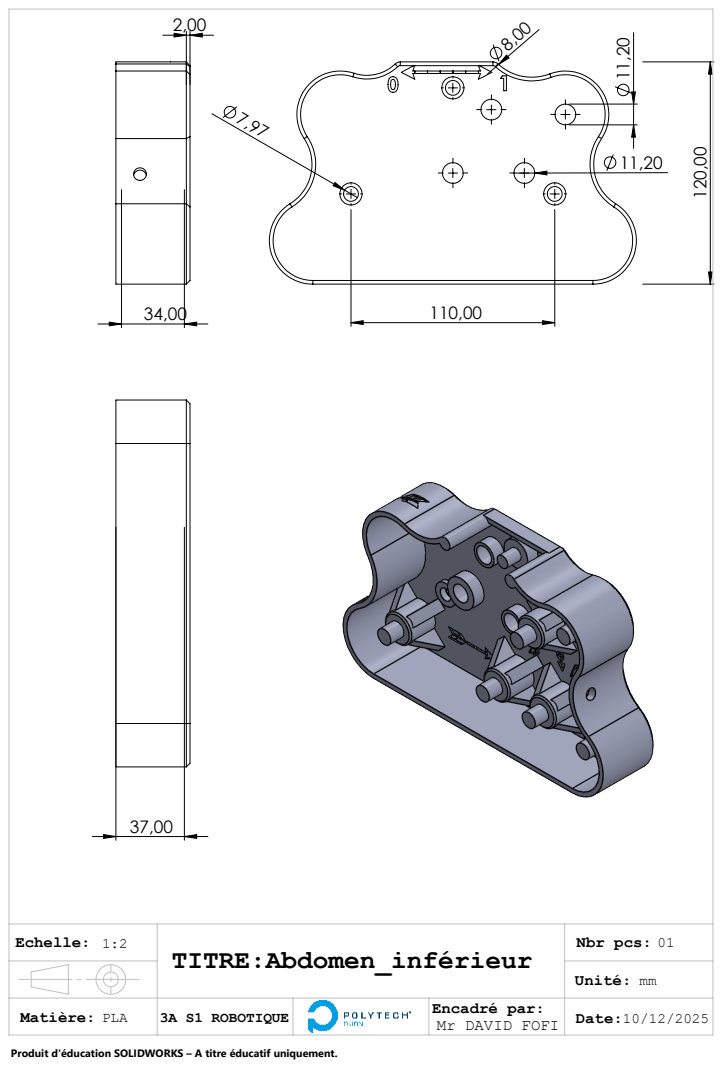
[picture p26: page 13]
Nbr pcs:

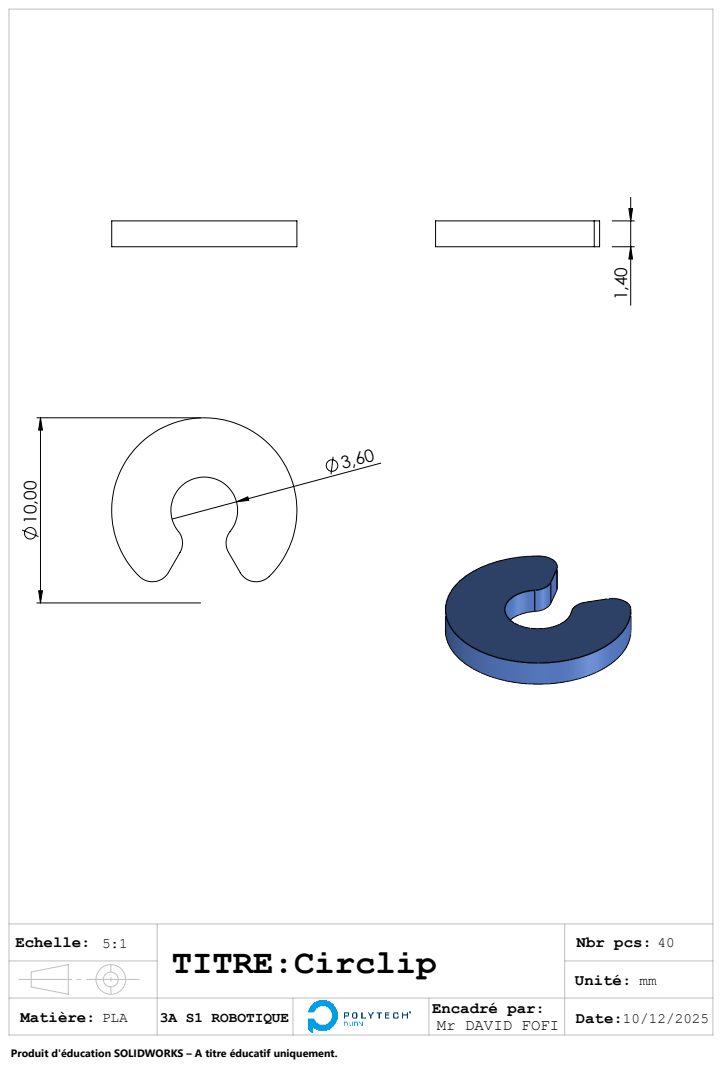
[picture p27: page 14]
Nbr pcs: Unité: TITRE:Circlip

Nbr pcs:

Nbr pcs:

TITRE:Entroises longues

Nbr pcs:

Nbr pcs:; Roue libre

Denture en chevron
Module : 2
Nb dents : 10

Nbr pcs:; Roue d'entrée

Nbr pcs:

Roue de sortie

Nbr pcs:

Poulie renvoi d'angle

Nbr pcs:

Nbr pcs:; Patella J

Nbr pcs:; Métatarse inférieure

Nbr pcs:

Nbr pcs:; Griffe supérieure
